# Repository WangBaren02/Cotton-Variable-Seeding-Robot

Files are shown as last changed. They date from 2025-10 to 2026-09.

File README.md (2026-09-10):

# 棉花变量播种机器人

Cotton Variable Seeding Robot

本项目面向棉花田间变量播种作业，构建了一套由移动底盘、距离与姿态感知、闭环运动控制、OpenMV 视觉节点、播种机构以及 PCB/机械设计资料组成的农业机器人系统。主控侧以 `STM32F407VG` 为核心，通过维特 IMU（WitMotion IMU）、6 路 Ultrasonic、2 路实际参与控制的 Encoder、GPIO 光电/作物检测信号和状态机、多组 PID，实现直行纠偏、垄端判断、换垄、出垄与停车等运动任务。

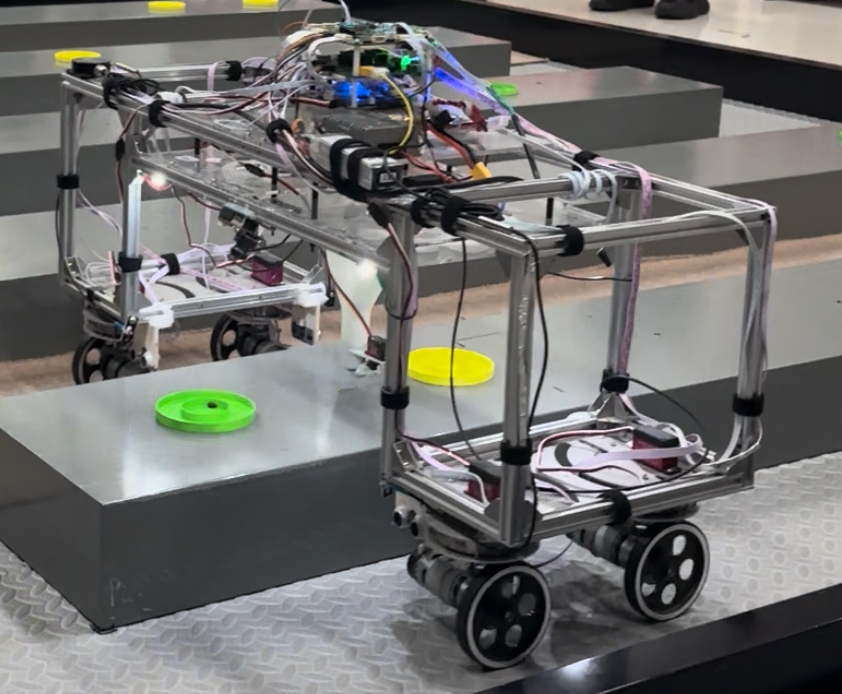
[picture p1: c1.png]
棉花变量播种机器人实机


▶ [点击观看棉花变量播种机器人实机演示](https://www.bilibili.com/video/BV1jCyhB8EZ5/)

## 项目简介

这个仓库不是单一的 MCU 示例程序，而是一个包含嵌入式控制、机器视觉、控制 PCB 和车体/播种机构设计资料的完整机器人项目。当前仓库中可以直接追踪的 Keil 工程位于 `CODE/USER/Prayer.uvprojx`，目标器件为 `STM32F407VG`，其运动控制主链包括：

- `TIM7` 周期中断调度任务；
- 维特 IMU 提供航向角反馈；
- 6 路 Ultrasonic 提供前方、左侧和右侧距离信息；
- TIM3/TIM5 对应的两路 Encoder 累计换垄位移；
- 4 路 DC Motor 和 4 路转向 Servo 执行底盘运动；
- `flag_step` 状态机选择不同的行驶、转向、换垄和出垄策略；
- OpenMV 通过颜色阈值与 Blob Detection 输出视觉/作业侧信号；
- `PCB板/` 与 `SOLIDWORKS 车体零件/` 保存控制板、车体、支架和播种机构资料。

## 技术栈与系统边界

| 模块 | 本仓库可核实的实现 |
| --- | --- |
| 主控 | `STM32F407VG`：`CODE/USER/Prayer.uvprojx` 的完整 Keil 工程目标 |
| 姿态感知 | 维特 IMU（WitMotion IMU）；主控通过 `USART2` 接收姿态数据并提取航向角 |
| 距离感知 | 6 路 Ultrasonic：`L1/L2`、`R1/R2`、`F1/F2`，使用 `TIM2` 与 `TIM9` 输入捕获 |
| 运动反馈 | 2 路实际被主程序初始化和读取的 Encoder：`TIM3`、`TIM5` |
| 边界/作物检测 | `LeftLight`、`RightLight` 两路 GPIO 信号，以及用于减速判断的 `PE15` GPIO 输入 |
| 视觉 | OpenMV：`RGB565`、`QVGA`、ROI、颜色阈值、均值滤波、Blob Detection |
| 底盘执行 | 4 路 DC Motor：`TIM1` 四通道 PWM + 方向 GPIO |
| 转向执行 | 4 路实际由 `Servo_Set_Angle()` 写入的转向 Servo：`TIM4` 四通道 PWM |
| 控制策略 | `flag_step` 状态机 + 航向 PID + 距离/纠偏 PID + 电机速度修正 |
| 工程资料 | Keil 工程、STM32 Standard Peripheral Library、OpenMV 脚本、PCB 工程压缩包、SolidWorks/SLDPRT/STL/DWG/DXF 文件 |

> 说明：PCB 资料和 `PCB板/TIPS.txt` 还提供了 `STM32F103RCT6` 作业板的证据，但仓库中没有找到对应的独立 Keil 源码工程。因此本文把它作为作业板/硬件资料证据说明，不把它包装成已由软件源码完整验证的第二套控制器。

## 项目亮点

- 使用 `STM32F407VG` 承担整车运动控制，`TIM7_IRQHandler()` 将状态判断、控制器选择、PWM 更新和 Ultrasonic 触发组织为周期任务。
- 维特 IMU 提供机器人航向角，主控以相对启动航向为目标，在直行、左右转向和倒车换垄阶段切换不同的航向控制器。
- 6 路 Ultrasonic 通过定时器输入捕获得到距离值，并经过限幅和均值滤波后参与垄端识别、侧向纠偏和换垄控制。
- 代码实际使用两路 Encoder 的累计位移完成换垄距离判断，避免把硬件资料中可能存在的编码器配置直接等同于当前固件使用数量。
- 多组 PID 分别面向航向、前方/侧方距离、转向 Servo 和电机速度修正，并根据 `flag_step` 选择当前作业状态所需的控制器。
- 4 路驱动电机、4 路转向 Servo、Ultrasonic、Encoder、光电信号和视觉/作业接口共同构成可追踪的机电闭环。
- OpenMV 采用轻量级颜色阈值与 Blob Detection，不依赖神经网络或深度学习模型。
- 仓库同时保留控制 PCB、车体连接板、Ultrasonic 支架、光电对管支架、Y 型作业机构、漏斗和作业机构上转盘等工程资料。

## 系统总体架构

```mermaid
flowchart TD
    ENV[棉田环境 / 垄道 / 作物目标] --> SENSE[多传感器感知]

    SENSE --> IMU[维特 IMU<br/>航向角]
    SENSE --> ULTRA[6 路 Ultrasonic<br/>L/R/F 距离]
    SENSE --> ENC[2 路 Encoder<br/>位移反馈]
    SENSE --> GPIO[GPIO 光电 / 作物检测]
    SENSE -. 视觉资料与作业接口 .-> MV[OpenMV<br/>RGB565 + Blob Detection]

    IMU --> MCU[STM32F407VG 主控]
    ULTRA --> MCU
    ENC --> MCU
    GPIO --> MCU
    MV -. GPIO / 作业板接口 .-> MCU

    MCU --> SCHED[TIM7 周期任务调度]
    SCHED --> FSM[flag_step 状态机<br/>任务状态选择]
    FSM --> PID[多组 PID / 运动控制策略]
    PID --> ACT[执行机构]
    ACT --> MOTOR[4 路 DC Motor]
    ACT --> SERVO[4 路转向 Servo]
    ACT -. 作业接口 .-> SEED[播种机构 / 作业板]
    MOTOR --> ROBOT[机器人运动、换垄与出垄]
    SERVO --> ROBOT
    ROBOT -. 运动反馈 .-> IMU
    ROBOT -. 距离 / 位移反馈 .-> ULTRA
    ROBOT -. Encoder 反馈 .-> ENC
```

图中的实线表示可以在当前 STM32F407 运动控制源码中直接追踪的链路；虚线表示仓库提供的 OpenMV、PCB 和播种机构资料与 GPIO/作业接口，但当前仓库没有提供完整的独立作业板固件和实车接线表。

## 实时控制与任务调度

`main.c` 的初始化顺序体现了主控的软件启动边界：Key、IO、LED、Servo PWM、Ultrasonic、OLED、Motor、`TIM7`、Encoder、PID 和 `USART1/USART2` 依次初始化。按下启动按键后，程序记录当前航向作为任务参考，写入各组航向 PID 的 `desired`，再置位 `flag_mission_start` 开始自动作业。

`TIM7_IRQHandler()` 内部使用多个软件计数器组织不同时间尺度的任务：

- 约 5 ms 控制分支：调用 `Detect_Flag_Step()`、`Detect_Flag_Slowdown()`、`Select_Servo_Angle()`、`Select_Motor_Speed()` 和 `Select_PID()`，随后统一写入 Servo 和 Motor 输出；
- 约 25 ms 触发一次 `Ultra_Trig()`，依次给 6 路 Ultrasonic 发送触发脉冲；
- 200 ms、500 ms、1000 ms、启动延时等标志用于状态切换后的停顿和减速节奏；
- OLED 实时显示航向、当前 `flag_step` 以及 6 路距离值，便于调试现场状态。

这种结构使“感知更新、状态判断、控制器选择、执行器更新”集中在固定周期内完成，而不是在主循环中用单一的 `Sensor → MCU → Motor` 直连逻辑表达。

## 运动控制系统

### 控制闭环

```mermaid
flowchart TD
    IMU[维特 IMU<br/>航向角] --> STATE[状态判断 / 控制策略]
    ULTRA[Ultrasonic<br/>前方与侧方距离] --> STATE
    ENC[Encoder<br/>换垄位移] --> STATE
    LIGHT[GPIO 光电 / 作物信号] --> STATE

    STATE --> SELECT["Select_PID()<br/>按 flag_step 选择控制器"]
    SELECT --> PID1[航向 PID]
    SELECT --> PID2[距离纠偏 PID]
    SELECT --> PID3[电机速度修正 PID]

    PID1 --> SERVO_CMD[Servo 角度增量]
    PID2 --> SERVO_CMD
    PID2 --> MOTOR_CMD[Motor 速度增量]
    PID3 --> MOTOR_CMD

    SERVO_CMD --> SERVO[4 路转向 Servo]
    MOTOR_CMD --> MOTOR[4 路 DC Motor]
    SERVO --> ROBOT[底盘运动]
    MOTOR --> ROBOT

    ROBOT -. 航向反馈 .-> IMU
    ROBOT -. 距离反馈 .-> ULTRA
    ROBOT -. 位移反馈 .-> ENC
```

### PID 的系统级分工

`pid.c` 中的 `PidObject` 统一保存目标值、误差、积分分离、积分限幅、微分项和输出限幅。README 只按控制目标进行抽象，不逐一罗列所有历史对象名：

- 航向闭环：直行、右向运动、左向运动、慢速转向、倒车和出垄阶段分别使用不同的航向 PID，将误差转换为 Servo 角度增量或四个电机的差速修正；
- 距离闭环：使用前方或侧方 Ultrasonic 距离与目标距离的误差，调整转向 Servo，使车体保持在目标通道/垄道关系中；
- 换垄闭环：在 `HuanLong()` 中使用 Encoder 的 `disA/disB` 作为位移判据，配合倒车电机方向、Servo 姿态和状态切换完成横向换垄；
- 电机速度闭环：PID 输出会叠加到 `SpeedL1/SpeedR1/SpeedL2/SpeedR2`，最终由 `Motor_Set_Speed()` 转换为四路 PWM 与方向信号；
- 状态相关控制：`Select_PID()` 根据 `flag_step` 决定当前使用航向、侧距、前距或换垄控制逻辑，避免所有阶段共用一组固定参数。

## 自动作业流程

源码中的 `flag_step` 不是单纯的数字流水号，而是对机器人作业动作的状态编码。按当前控制代码可还原为以下流程：

```mermaid
stateDiagram-v2
    [*] --> S0: 按键启动

    S0: 0 初始直行 / 启动延时
    S1: 1 右向转向或横移
    S2: 2 右侧换垄倒车
    S3: 3 左向转向或横移
    S4: 4 左侧换垄倒车
    S5: 5 右向转向或横移
    S6: 6 右侧换垄倒车
    S7: 7 左向转向或横移
    S8: 8 左侧换垄倒车
    S9: 9 最后一轮右向运动
    S10: 10 最后一轮左向 / 出垄准备
    S11: 11 出垄倒车
    S12: 12 停车

    S0 --> S1: F1/F2 距离达到垄端条件
    S1 --> S2: LightStop 检测到垄端光电事件
    S2 --> S3: HuanLong 中 disA 达到目标
    S3 --> S4: LightStop 检测到另一侧垄端
    S4 --> S5: HuanLong 中 disA 达到目标
    S5 --> S6: LightStop 检测到垄端
    S6 --> S7: HuanLong 中 disA 达到目标
    S7 --> S8: LightStop 检测到另一侧垄端
    S8 --> S9: HuanLong 中 disA 达到目标
    S9 --> S10: LightStop + 减速延时
    S10 --> S11: LightStop 完成最后边界判断
    S11 --> S12: ChuLong 中 disB 达到出垄距离
    S12 --> [*]
```

其中，`HuanLong()` 先让底盘倒车并读取两路 Encoder 的累计位移，达到当前状态对应的距离后停车、切换 Servo 姿态并进入下一状态；最后的 `ChuLong()` 使用另一方向的位移条件完成出垄并清除 `flag_mission_start`。

## 多传感器感知

### 维特 IMU

实际机器人使用维特 IMU。主控的 `USART2` 驱动接收固定长度姿态帧，检查 `0x55/0x53` 帧头后提取航向角数据，并减去启动时记录的 `start_YAW`，再根据初始朝向完成角度回绕。控制层中的历史变量和 PID 对象名称可能保留旧项目命名，但 README 按真实硬件统一写为维特 IMU（WitMotion IMU）。

### 6 路 Ultrasonic

`ultrasonic.h` 明确给出了六个测距通道：

- 左侧：`L1`、`L2`；
- 右侧：`R1`、`R2`；
- 前方：`F1`、`F2`。

`TIM2` 负责四路侧向回波输入捕获，`TIM9` 负责两路前向回波输入捕获。每一路根据上升沿/下降沿时间计算距离，并执行限幅和 `MeanFilterLimit()` 均值滤波。代码中的 `Ultra_Trig()` 依次触发六个通道；PCB 资料也特别提醒不要同时开启六路，以降低声波串扰。

### Encoder

当前 F407 主程序只调用：

- `TIM3_EncoderB_Init()`；
- `TIM5_EncoderA_Init()`；
- `Read_Encoder_Cnt()`。

`Encoders` 结构体保存 `cntA/cntB`、速度和累计位移 `disA/disB`。在换垄状态中，`disA` 和 `disB` 被清零并重新累计，用于判断横向移动和出垄距离。因此 README 写“2 路实际软件反馈”，不把历史 README 中的“4 encoders”当作当前固件事实。

### GPIO 光电与按键

`LeftLight` 和 `RightLight` 由两个 GPIO 输入宏提供，`LightStop()` 根据信号的边沿历史判断垄端事件；`PE15` 被读取为作物/颜色减速信号，在特定转向状态中触发 `Motor_SlowDown()`。此外，4 个按键用于启动、调试和手动操作，OLED 显示当前航向、状态和距离值。

仓库中还存在 `TFLuna` 驱动，但其 `LASER` 宏为关闭状态，当前 README 不把它列为已启用的主感知链路。

## 机器视觉

OpenMV 目录提供两份按左右位置命名的脚本：`RIGX.txt` 和 `LEFX.txt`。两份脚本都体现了以下视觉处理链：

1. 使用 `RGB565`、`QVGA`，关闭自动增益和自动白平衡；
2. 在 ROI 内分别使用绿色和黄色 `Color Threshold`；
3. 对图像做一次均值处理，并调用 `find_blobs()`；
4. 从候选 Blob 中选择最大色块，输出颜色和“多个色块”状态；
5. 通过 OpenMV 的 `P4/P5/P6` GPIO 输出二值信号。

这是一套基于颜色阈值和 Blob Detection 的轻量级视觉方案，不应描述为 AI、Deep Learning 或神经网络目标检测。目录中另有 `2022DFH（森哥）.txt` 历史版本，其中包含 `UART3` 和数据打包函数，但当前代码中的发送调用被注释，不能直接当作当前实机的串口视觉通信链路。

## 播种执行机构

播种部分在仓库中以“视觉脚本 + 作业接口 + PCB 资料 + 机械资料”的形式出现：

- OpenMV 脚本输出颜色/色块状态，供作业侧使用；
- F407 控制代码中的 `Detect_Flag_Mv()` 根据当前运动状态和左右光电信号驱动 `PE7/PE8` 作业接口；
- `PCB板/ProProject_智能农装大赛_2024-05-16.zip` 与 `PCB板/TIPS.txt` 提供了作业板资料，资料中出现 `STM32F103RCT6`；
- `SOLIDWORKS 车体零件/` 包含 Y 型作业机构、漏斗、作业机构上转盘、光电对管支架和相关 STL/SLDPRT 文件。

当前仓库没有找到 STM32F103 作业板对应的独立 Keil 源码，也没有一条从视觉输出到播种 Servo/转盘的完整可编译调用链。因此，本节展示已存在的系统集成证据，同时明确不把缺失的板间控制细节包装成当前 F407 工程已经完全实现的功能。

## 硬件与机械设计

仓库包含以下非纯软件工程资料：

- `PCB板/`：嘉立创 EDA 专业版工程压缩包及打开说明；资料文本中同时可见主控板 `STM32F407VGT6` 与作业板 `STM32F103RCT6` 的硬件证据；
- `SOLIDWORKS 车体零件/`：车体连接板、Ultrasonic 支架、光电对管支架、亚克力板图纸、Y 型作业机构、漏斗和上转盘等模型/加工文件；
- `c1.png`：机器人实机照片；
- `CODE/USER/Prayer.uvprojx`：可在 Keil 中打开的 STM32F407 主控工程。

PCB 目录中的说明还记录了六路 Ultrasonic 的串扰注意事项、作业板供电/端子约束以及实车接线可能与板上丝印存在差异。README 因此只使用源码和资料共同能证明的系统级表述，不把 PCB 丝印直接当作软件调用关系。

## 软件结构

```text
CODE/
├── CORE/                  # CMSIS Cortex-M4 头文件与启动文件
├── DMP/                   # 历史惯性传感器算法/协议相关资料
├── FWLIB/                 # STM32F4 Standard Peripheral Library
├── HARDWARE/
│   ├── ENCODER/           # Encoder 初始化、计数、位移与速度处理
│   ├── MOTOR/             # 四路电机 PWM 与方向控制
│   ├── SERVO/             # Servo PWM 与角度输出
│   ├── ULTRASONIC/        # 六路 Ultrasonic 触发与输入捕获
│   ├── USART*_DMA/        # USART DMA 收发驱动
│   ├── TIMER7/            # 周期调度定时器
│   ├── IO/                # 作业接口和 GPIO 输入/输出
│   ├── wit_c_sdk/         # 维特传感器协议 SDK 资料
│   ├── TFLUNA/            # TFLuna 驱动（当前宏配置未启用）
│   └── ...
├── OBJ/                   # Keil 编译生成的目标文件与报告
├── SYSTEM/
│   ├── CONTROL/           # 状态机、任务策略、行驶/换垄/出垄控制
│   ├── PID/               # PID 对象、更新算法和控制量映射
│   ├── delay/             # 延时服务
│   └── sys/               # 系统底层初始化
└── USER/
    ├── main.c             # 主程序、外设初始化和任务启动
    └── Prayer.uvprojx     # Keil 工程文件，目标为 STM32F407VG

摄像头识别代码（openmv）/
├── RIGX.txt               # 右侧命名的颜色识别脚本
├── LEFX.txt               # 左侧命名的颜色识别脚本
└── 2022DFH（森哥）.txt    # 历史版本，包含未启用的 UART 发送实现
```

目录结构保持项目原貌；本次维护只更新 README，不重命名、不移动、不清理源码或历史目录。

## 项目演示

▶ [点击观看：第九届农装 B 类国二获奖作品——棉花变量播种机器人](https://www.bilibili.com/video/BV1jCyhB8EZ5/)

## 项目成果

项目参加 **第九届国际大学生智能农业装备创新大赛**，获得 **全国二等奖**。相关竞赛要求可参考[官方竞赛页面](https://uiaec.ujs.edu.cn/news_show.php?id=190)。比赛背景是项目成果的一部分，但本 README 将重点放在机器人本体、控制链路和可验证的工程资料上。

## 仓库说明

- 本 README 按真实硬件将姿态感知写为维特 IMU（WitMotion IMU）；源码中的历史变量、PID 对象和目录名称不作为最终硬件架构依据。
- 主控软件证据以 `CODE/USER/Prayer.uvprojx`、`CODE/USER/main.c`、`CODE/SYSTEM/CONTROL/`、`CODE/SYSTEM/PID/` 和 `CODE/HARDWARE/` 中的实际调用关系为准。
- `STM32F103RCT6` 目前只有 PCB/作业板资料证据，未在仓库中找到同等完整的独立固件工程。
- OpenMV 目录有两份左右命名脚本，但当前仓库没有单独的摄像头部署清单和实车接线图；视觉节点的物理数量、主控归属和最终板间连接仍应以实车资料补充确认。
- `CODE/HARDWARE/` 中保留了多类历史驱动和编译产物；本 README 不把“目录存在”直接等同于“当前实机正在启用”。

## License

本仓库当前声明为 [MIT License](./LICENSE)。仓库内第三方库、器件厂商 SDK 和工具生成文件如带有独立许可或使用条件，应同时遵循其原始许可。

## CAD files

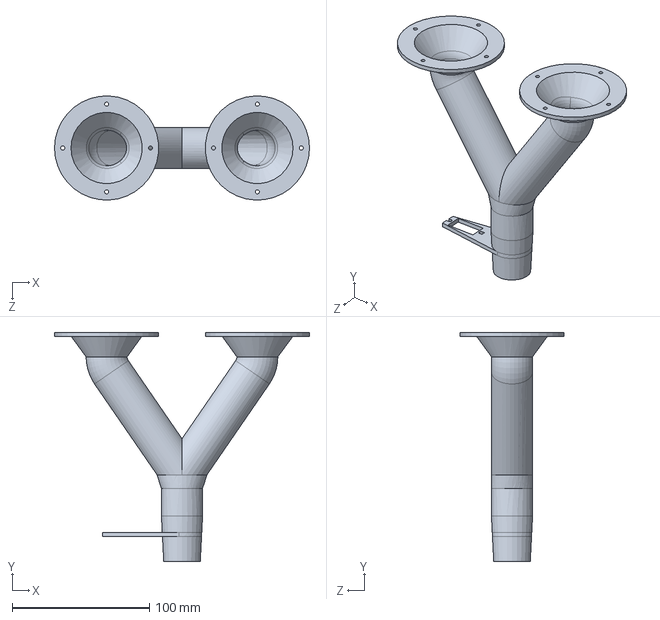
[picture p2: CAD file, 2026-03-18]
SOLIDWORKS 车体零件/Y型作业机构/最初版.SLDPRT
186.0 x 167.2 x 75.9 mm

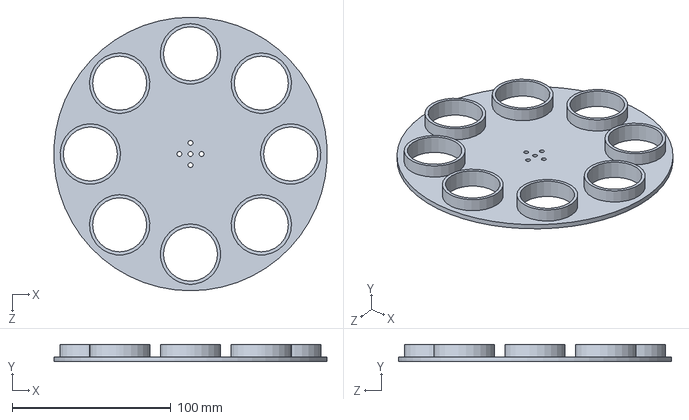
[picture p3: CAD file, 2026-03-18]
SOLIDWORKS 车体零件/作业机构上转盘/作业机构上转盘.SLDPRT
171.7 x 11.0 x 172.0 mm

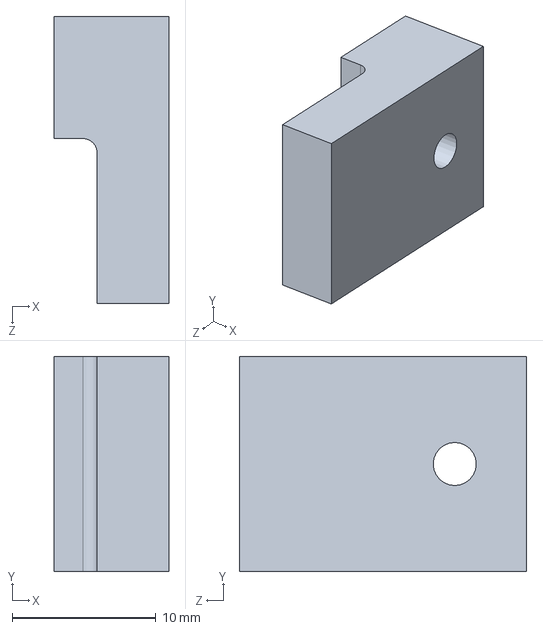
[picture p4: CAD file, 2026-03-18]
SOLIDWORKS 车体零件/光电对管支架/光电对管支架.SLDPRT
8.00 x 15.0 x 20.0 mm

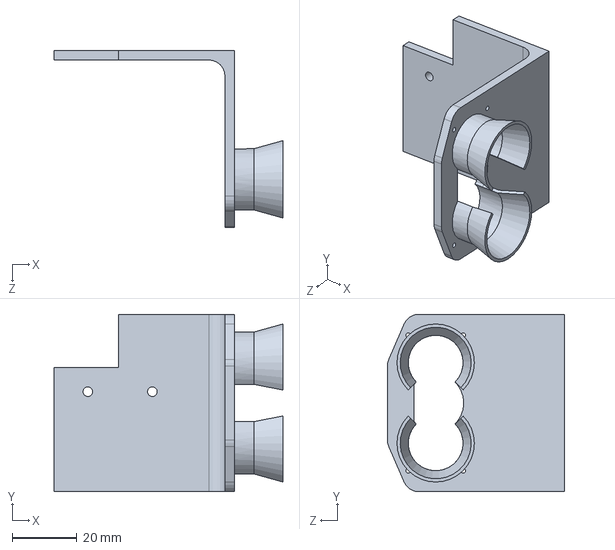
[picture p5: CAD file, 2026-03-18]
SOLIDWORKS 车体零件/超声波支架/RIGXXX.SLDPRT
71.0 x 55.0 x 55.0 mm

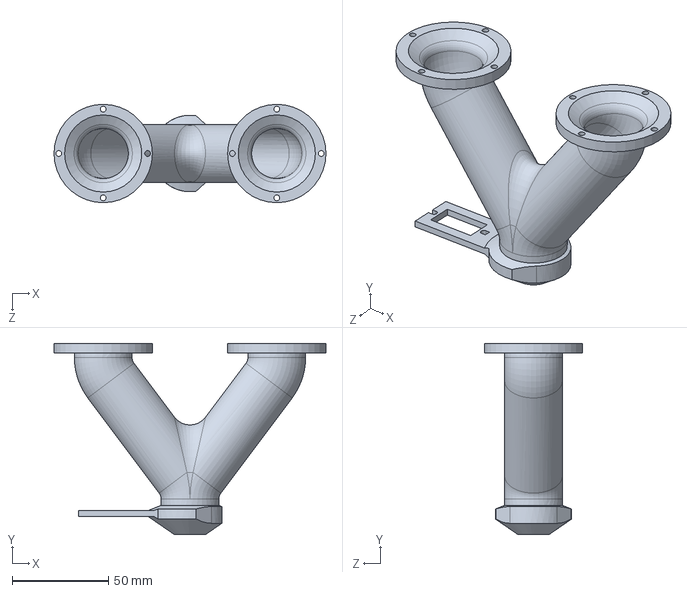
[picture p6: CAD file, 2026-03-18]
SOLIDWORKS 车体零件/Y型作业机构/漏斗XXXXX.SLDPRT
141.0 x 99.2 x 51.0 mm

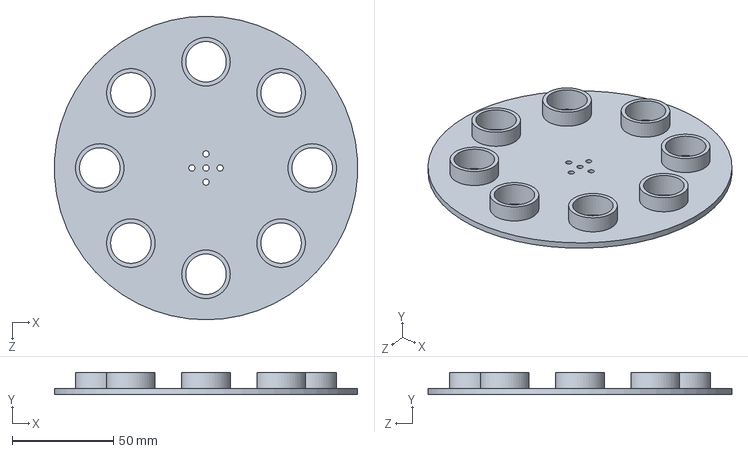
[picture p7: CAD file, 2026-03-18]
SOLIDWORKS 车体零件/作业机构上转盘/001X.SLDPRT
149.7 x 11.0 x 150.0 mm

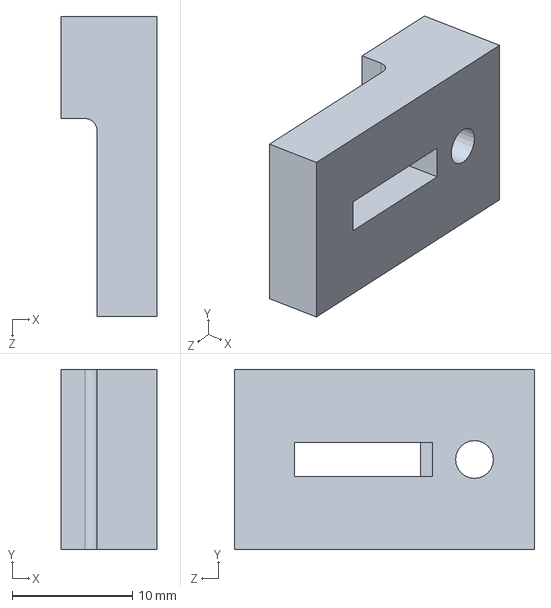
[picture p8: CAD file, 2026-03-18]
SOLIDWORKS 车体零件/光电对管支架/0005X.SLDPRT
8.00 x 15.0 x 25.0 mm

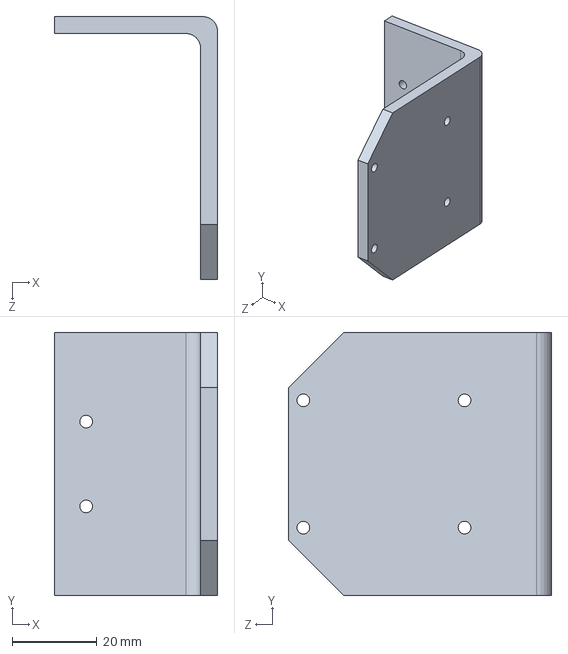
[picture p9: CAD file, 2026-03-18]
SOLIDWORKS 车体零件/超声波支架/MIDX.SLDPRT
38.5 x 62.0 x 62.0 mm

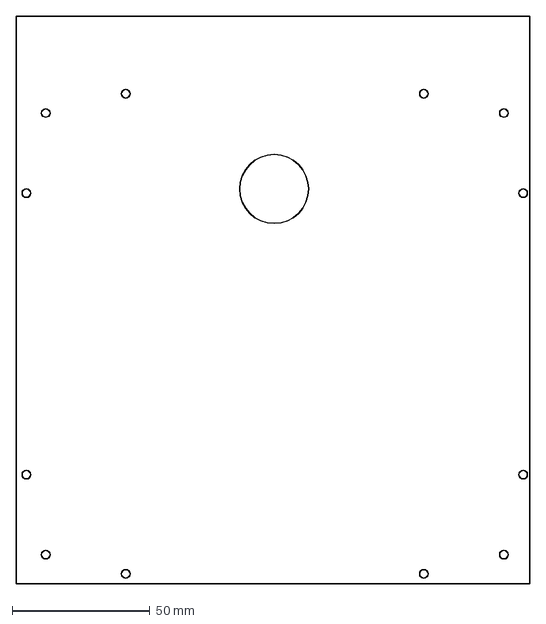
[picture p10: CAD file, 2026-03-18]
SOLIDWORKS 车体零件/亚克力板/02X.dxf
186.0 x 205.5 mm

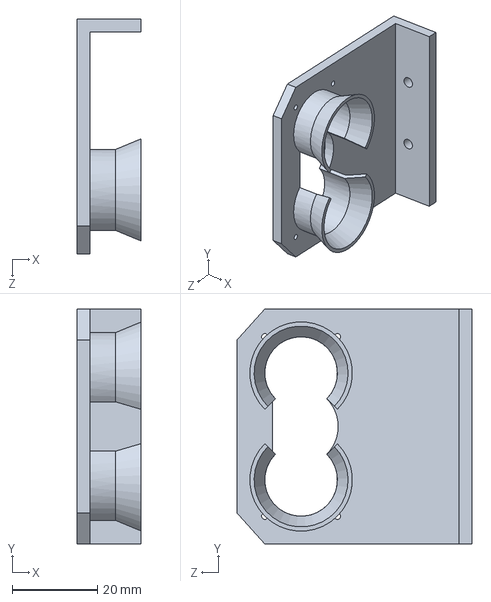
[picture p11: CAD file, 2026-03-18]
SOLIDWORKS 车体零件/超声波支架/MIDXXX.SLDPRT
15.0 x 55.0 x 55.0 mm

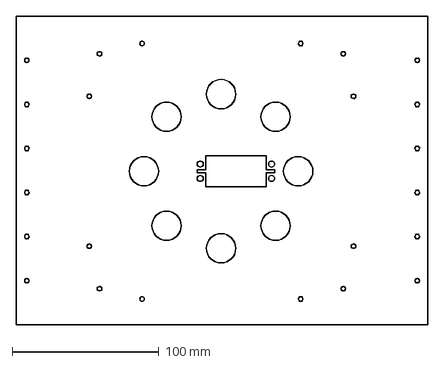
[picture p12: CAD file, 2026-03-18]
SOLIDWORKS 车体零件/亚克力板/01X.dxf
280.0 x 210.0 mm

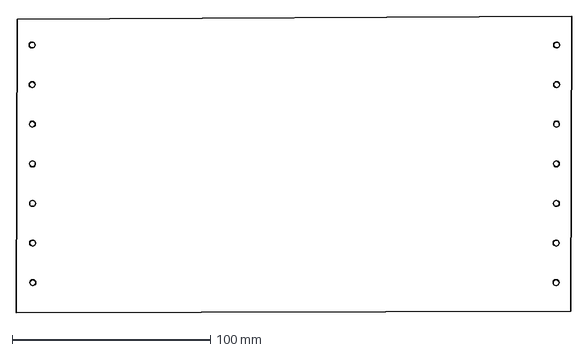
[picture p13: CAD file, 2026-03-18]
SOLIDWORKS 车体零件/亚克力板/00X.dxf
280.4 x 149.7 mm

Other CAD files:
SOLIDWORKS 车体零件/亚克力板/01.dwg
SOLIDWORKS 车体零件/轮子与框架连接板.DWG
SOLIDWORKS 车体零件/亚克力板/02.dwg
SOLIDWORKS 车体零件/打板子（2022）.SLDPRT
SOLIDWORKS 车体零件/超声波支架/LEFXXX.SLDPRT
SOLIDWORKS 车体零件/超声波支架/LEFX.SLDPRT
SOLIDWORKS 车体零件/Y型作业机构/漏斗XXXXX.STL
SOLIDWORKS 车体零件/亚克力板/00.dwg
SOLIDWORKS 车体零件/亚克力板/02X.dwg
SOLIDWORKS 车体零件/作业机构上转盘/001X.STL
SOLIDWORKS 车体零件/光电对管支架/0005X.STL
SOLIDWORKS 车体零件/光电对管支架/光电对管支架.STL
SOLIDWORKS 车体零件/超声波支架/LEFX.STL
SOLIDWORKS 车体零件/超声波支架/LEFXX.SLDPRT
SOLIDWORKS 车体零件/超声波支架/LEFXX.STL
SOLIDWORKS 车体零件/超声波支架/LEFXXX.STL
SOLIDWORKS 车体零件/超声波支架/MIDX.STL
SOLIDWORKS 车体零件/超声波支架/MIDXX.SLDPRT
SOLIDWORKS 车体零件/超声波支架/MIDXX.STL
SOLIDWORKS 车体零件/超声波支架/MIDXXX.STL
SOLIDWORKS 车体零件/超声波支架/MIDXXXX.STL
SOLIDWORKS 车体零件/超声波支架/RIGX.SLDPRT
SOLIDWORKS 车体零件/超声波支架/RIGX.STL
SOLIDWORKS 车体零件/超声波支架/RIGXX.SLDPRT
SOLIDWORKS 车体零件/超声波支架/RIGXX.STL
SOLIDWORKS 车体零件/超声波支架/RIGXXX.STL

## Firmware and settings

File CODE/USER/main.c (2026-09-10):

#include "stdio.h"
#include "string.h"
#include "sys.h"
#include "delay.h"
#include "stm32f4xx.h"
#include "control.h"
//#include "lamp.h"
#include "led.h"
#include "beep.h"
#include "key.h"
#include "oled.h"
#include "usart1_dma.h"
#include "usart2_dma.h"
#include "usart3_dma.h"
#include "uart4_dma.h"
#include "timer7.h"
#include "servo.h"
#include "ultrasonic.h"
#include "motor.h"
#include "encoder.h"
#include "pid.h"
#include "io.h"

float start_yaw=0;

int main(void)
{
	//系统初始化
	u8 key;
	float yaw_t;
	NVIC_PriorityGroupConfig(NVIC_PriorityGroup_2);
	delay_init(168);
	//BEEP_Init();
	Key_Init();
	IO_init();
	LED_Init();
	TIM4_Servo_PWM_Init(20000,84);
	Ultrasonic_Init();
	OLED_Init();
	OLED_Display_On();
	OLED_Clear();
	Motor_Init();
	TIM7_Init(1000,84);
	TIM3_EncoderB_Init(0xFFFF,1);
	TIM5_EncoderA_Init(0xFFFF,1);
	PID_Init();
	Motor_Stop();
	Motor_Set_Speed();
	USART1_Init(115200);
	USART2_Init(9600);

	Servo1_Increase = 0;
	Servo2_Increase = 0;
	Servo3_Increase = 0;
	Servo4_Increase = 0;
	SpeedL1_Increase = 0;
	SpeedR1_Increase = 0;
	SpeedL2_Increase = 0;
	SpeedR2_Increase = 0;
	SpeedL1_Increase_9250 = 0;
	SpeedR1_Increase_9250 = 0;
	SpeedL2_Increase_9250 = 0;
	SpeedR2_Increase_9250 = 0;
//	LED1_ON;
	
	Servo_Forw();
//	Servo_Turn();
	Servo_Set_Angle();
	while(1)
	{
		key = Key_Scan();
		if(key == 1)
		{
			start_YAW=yaw;					//记录下当前指南针原始中心角度
			if(start_YAW>-180 && start_YAW<-135)mode=2;
			else if(start_YAW<180 && start_YAW>135)mode=3;

			delay_ms(100);			//等待yaw稳定
			
			start_yaw=yaw;
			PID_9250_Forward_motor.desired = start_yaw;
			PID_9250_Forward.desired = start_yaw;
			PID_9250_Right.desired = start_yaw;
			PID_9250_Left.desired = start_yaw;
			PID_9250_Right_slow.desired = start_yaw;
			PID_9250_Left_slow.desired = start_yaw;
			PID_9250_Back.desired = start_yaw;
			PID_9250_Back_last.desired = start_yaw;
			PID_9250_Back_last_motor.desired = start_yaw;
			flag_mission_start = 1;
			flag_delay_1500ms = 1;	//step0时开始2s后以60%速度继续行驶
		}
		
		if(key == 2)
		{
			flag_step += 2;
//			PID_F1_Left_Servo.kp+=0.1;
//			PID_F1_Left_Servo.kp+=0.1;
		}
		
		if(key == 3)
		{
//			start_YAW=yaw;					//记录下当前指南针原始中心角度
//			if(start_YAW>-180 && start_YAW<-135)mode=2;
//			else if(start_YAW<180 && start_YAW>135)mode=3;
//			PID_9250_Right.kd+=2;
		}
		
		if(key == 4)
		{
			delay_ms(100);
//			Motor_Forw();
//			Motor_Right();
//			Motor_Left();
//			Motor_Back();
//			Motor_Set_Speed();
			Servo_Forw();
			Servo_Set_Angle();
		}
		
		
		delay_us(20);
		OLED_Show3FNum(10,0,yaw ,4,2,12);
		OLED_ShowIntNum(64,0,flag_step,2,12);
		//OLED_ShowIntNum(84,0,flag_huanlong,1,12);
		//OLED_ShowIntNum(96,0,flag_chulong,1,12);
		
//		OLED_Show3FNum(64,0 ,	PID_9250_Back.kp,3,1,12);
//		OLED_Show3FNum(10,12 ,	PID_9250_Back.kd,3,1,12);
		
		
//		OLED_Show3FNum(0,36,PID_9250_Right.kp,5,2,12);
//		OLED_Show3FNum(48,36,PID_9250_Right.kd,5,2,12);
/*********************************************************/
		OLED_Show3FNum(0,12,ultra_F1.DIS ,5,2,12);
		OLED_Show3FNum(48,12,ultra_F2.DIS ,5,2,12);

		OLED_Show3FNum(0,24,ultra_L1.DIS ,5,2,12);
		OLED_Show3FNum(48,24,ultra_L2.DIS,5,2,12);
		
		OLED_Show3FNum(0,36,ultra_R1.DIS ,5,2,12);
		OLED_Show3FNum(48,36,ultra_R2.DIS ,5,2,12);
    
//		OLED_Show3FNum(10,48,RightLightLast ,1,0,12);
//		OLED_Show3FNum(24,48,LeftLightLast ,1,0,12);
//		OLED_Show3FNum(36,48,RightLight ,1,0,12);
//		OLED_Show3FNum(48,48,LeftLight ,1,0,12);
//		OLED_Show3FNum(10,48,PID_F1_Left_Servo.kp ,1,3,12);
//		OLED_Show3FNum(48,48,PID_F1_Left_Servo.kd ,1,3,12);
	  OLED_Refresh_Gram();
	}
}

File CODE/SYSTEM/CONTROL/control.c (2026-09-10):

/* 23年东方红控制代码 
   编写人：周段文诚（原杨少文改）
	 时间：2023.4.25
	             头
			   R1----------L1
				 |            |
				 |            |
				 |            |
				 |            |
				 |            |
				 |            |
				 |            |
				 |            |
				 |            |
				 R2---------- L2
				       人
*/
/*
2024 沈子杰
		         F1头F2
			   L1----------R1
				 |            |
				 |            |
				 |            |
				 |            |
				 |            |
				 |            |
				 |            |
				 |            |
				 |            |
				 L2---------- R2
				       尾
							 人
*/
#include "stdio.h"
#include "string.h"
#include "control.h"
#include "sys.h"
#include "delay.h"
//#include "lamp.h"
#include "led.h"
#include "usart1_dma.h"
#include "usart2_dma.h"
#include "usart3_dma.h"
#include "uart4_dma.h"
#include "ultrasonic.h"
#include "oled.h"
#include "encoder.h"
#include "param.h"
#include "motor.h"
#include "pid.h"
#include "servo.h"
#include "io.h"

#define N 0.98
#define Move 185          //直行停车预留量420
#define move 320          //右行停车预留量 190
#define movez 320         //左行停车预留量 190
#define movez_last 350		//出垄前左行停车预留量

u8 parity						 = 0;								//判断奇数偶
float pitch, roll;
extern float yaw;
short aacx, aacy, aacz;
short gyrox, gyroy, gyroz;
u8 flag_step = 0;					//判断现在运行到了第几步的标志
u8 flag_yaw_new = 0;

char PIDOUT[20];
//int a=0;
/***********************************周段文诚 2022.9.14********************************************
0：入长垄          
1：→1
2：↓1
3：←1
4：↓2
5：→2
6：↓3
7：←2
8：↓4
9：→3
10：←3
11：出垄
12：停车
***********************************************************************************************/
u8 flag_mission_start 		= 0;				//按键按下后，进入控制函数的标志
u8 flag_huanlong 				  = 0;				//换垄标志，此flag=1时正在换垄
u8 flag_chulong 				  = 0;				//出笼标志，此flag=1时已经出笼
u8 flag_slowdown 				  = 0;				//减速标志，此flag=1时表示需要减速
u8 flag_zuowuslowdown 		= 0;				//减速标志，此flag=1时表示需要减速
u8 flag_found_zuowu				= 0;				//检测作物的标志，此flag=1时表示检测到作物，开始减速
u8 flag_delay					    = 0;				//延时标志，此flag=1时表示需要延时
u8 flag_delay_200ms				= 0;				//延时标志，此flag=1时表示需要延时200ms
u8 flag_delay_500ms				= 0;				//延时标志，此flag=1时表示需要延时500ms
u8 flag_delay_1000ms			= 0;				//延时标志，此flag=1时表示需要延时1000ms
u8 flag_delay_1500ms			= 0;				//延时标志，此flag=1时表示需要延时1500ms
u8 flag_delay_zuowu				= 0;				//延时标志，此flag=1时作物表示需要延时
u8 Color_SLOW							=0;
u8 flag_step0SLOW					=0;
uint8_t RightLightLast = 2;
uint8_t LeftLightLast = 2;

//float N_F_R = 1.0;
//根据不同步数选择舵机、电机的基本角度、速度
float Servo1_Base = 90, Servo2_Base = 90, Servo3_Base = 90, Servo4_Base = 90;
float Servo5_Base = 0, Servo6_Base = 0, Servo7_Base = 0, Servo8_Base = 0;
float SpeedL1_Base = 0, SpeedR1_Base = 0, SpeedL2_Base = 0, SpeedR2_Base = 0;
float SpeedL1_Base_c = 0, SpeedR1_Base_c = 0, SpeedL2_Base_c = 0, SpeedR2_Base_c = 0;
//根据PID的结果得到的舵机、电机的增量
float Servo1_Increase = 0, Servo2_Increase = 0, Servo3_Increase = 0, Servo4_Increase = 0;
float Servo5_Increase = 0, Servo6_Increase = 0, Servo7_Increase = 0, Servo8_Increase = 0;
float SpeedL1_Increase = 0, SpeedR1_Increase = 0, SpeedL2_Increase = 0, SpeedR2_Increase = 0;
float SpeedL1_Increase_9250 = 0, SpeedR1_Increase_9250 = 0, SpeedL2_Increase_9250 = 0, SpeedR2_Increase_9250 = 0;
//调试基础电机速度
//float Motor_Forw_test_L1 = 0, Motor_Forw_test_L2 = 0, Motor_Forw_test_R1 = 0, Motor_Forw_test_R2 = 0;
void TIM7_IRQHandler()
{

    static u16 time_1ms;
    static u16 time_5ms;
    static u16 time_10ms;
    static u16 time_25ms;
    static u16 time_50ms;
    static u16 time_200ms;
    static u16 time_500ms;
    static u16 time_1000ms;
    static u16 time_1500ms;
    static u16 time_zuowu;
    static u16 lamp_1000ms;

    if(TIM_GetITStatus(TIM7, TIM_IT_Update) == SET) //溢出中断
    {
        if(flag_mission_start == 1)		//按键按下后1、5、10、50ms的任务才能进行
        {
            time_1ms++;
            time_5ms++;
            time_10ms++;
            time_50ms++;
        }

        //下面的则不受按键的影响
        time_25ms++;


        if(flag_delay_200ms)								//延时专用
        {
            time_200ms++;
        }

        if(flag_delay_500ms)
        {
            time_500ms++;
        }

        if(flag_delay_1000ms)
        {
            time_1000ms++;
        }

        if(flag_delay_1500ms)
        {
            time_1500ms++;
        }

        if(flag_delay_zuowu)
        {
            time_zuowu++;
        }

//----------------------------------------------------------------------
        if(time_1ms == 1)
        {
            time_1ms = 0;

        }

//----------------------------------------------------------------------
        if(time_5ms == 5)
        {
					time_5ms = 0;
					Detect_Flag_Step();				//判断运行到第几步了

					Detect_Flag_Mv();
					flag_delay = (flag_delay_200ms || flag_delay_500ms || flag_delay_1000ms);

					if(!flag_delay)						//在不需要延时的时候才运行下面的步骤
					{
							Detect_Flag_Slowdown();		//判断是否需要减速
							Select_Servo_Angle();			//根据步数选择舵机基本角度
							Select_Motor_Speed();			//根据步数选择电机基本速度
							Select_PID();							//根据当前运行的步数来选择用那个PID

							Servo_Set_Angle();				//设置舵机角度
							Motor_Set_Speed();				//设置电机转速

							if(!flag_huanlong)
							{
									TIM5->CNT = 0;
									TIM3->CNT = 0;
									Encoders.disA = 0;
									Encoders.disB = 0;
							}

							if(flag_huanlong)
							{
									Read_Encoder_Cnt();
							}
					}
					if(!flag_delay)
					{
						if(flag_huanlong&&!flag_chulong)
						{
							HuanLong();								//换垄，当换完垄后，flag_step会+1
						}

						if(flag_chulong)
						{
							ChuLong();
						}
					 }

        }
//----------------------------------------------------------------------
        if(time_10ms == 10)
        {
          time_10ms = 0;
//					sprintf(PIDOUT,"%f,%f\n",ultra_F1.DIS,yaw);
//					sprintf(PIDOUT,"%f,%f\n",ultra_F1.DIS,ultra_F2.DIS);
//					USART1_DMATransfer((uint32_t *)PIDOUT,strlen(PIDOUT));
        }

//----------------------------------------------------------------------
        if(time_25ms == 25)
        {
            time_25ms = 0;

            Ultra_Trig();
						//Yaw_new();
        }

//----------------------------------------------------------------------
        if(time_50ms == 50)
        {
            time_50ms = 0;
        }

//----------------------------------------------------------------------
        if(time_200ms == 200)
        {
            time_200ms = 0;

            flag_delay_200ms = 0;
        }

//----------------------------------------------------------------------
        if(time_500ms == 450)
        {
            time_500ms = 0;

            flag_delay_500ms = 0;
        }

//----------------------------------------------------------------------
        if(time_1000ms == 680)	//700
        {
            time_1000ms = 0;

            flag_delay_1000ms = 0;
        }
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

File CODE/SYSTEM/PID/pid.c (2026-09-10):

#include "pid.h"
#include "math.h"
#include "motor.h"
#include "control.h"

#define n 1
#define speed_r_l 100
#define speed_r 80
#define speed_l 80

#define speed_r_9250 5
#define speed_l_9250 5

#define speed_r_9250_s 0.6
#define speed_l_9250_s 0.6

#define speed_r_back 120
#define speed_l_back 120

#define speed_r_j 100
#define speed_l_j 100

#define speed_r_r 100
#define speed_l_r 100

//电机A和电机B的转速闭环PID
PidObject PID_PWMA;
PidObject PID_PWMB;
//直走时的9250闭环
PidObject PID_9250_Forward;
PidObject PID_9250_Forward_motor;
//向右走的9250闭环
PidObject PID_9250_Right;
//向左走的9250闭环
PidObject PID_9250_Left;

//向右走的9250闭环
PidObject PID_9250_Right_slow;
//向左走的9250闭环
PidObject PID_9250_Left_slow;
//向后走的9250闭环
PidObject PID_9250_Back;
PidObject PID_9250_Back_last;
PidObject PID_9250_Back_last_motor;
//靠左前行时舵机进行闭环
PidObject PID_L1_For_Servo;
PidObject PID_L2_For_Servo;

//靠左后退时舵机进行闭环
PidObject PID_L1_Back_Servo;
PidObject PID_L2_Back_Servo;

//靠右前行时舵机进行闭环
PidObject PID_R1_For_Servo;

//靠右后退时舵机进行闭环
PidObject PID_R2_Back_Servo;
PidObject PID_R1_Back_Servo;
//舵机左行右行
PidObject PID_F1_Left_Servo;
PidObject PID_F2_Left_Servo;
PidObject PID_F1_Right_Servo;
PidObject PID_F2_Right_Servo;

//电机左行右行
PidObject PID_F1_Left_Motor;
PidObject PID_F2_Right_Motor;

PidObject PID_L1_For_Motor;
PidObject PID_L2_For_Motor;

//换垄时，用舵机保持和垄的固定距离
PidObject PID_Back_L_Servo;
PidObject PID_Back_R_Servo;

PidObject PID_L1_Left_Servo;
PidObject PID_R1_Right_Servo;

void PID_Init(void)
{
	PID_R1_Right_Servo.desired = R1 - R2;
	//比例
	PID_R1_Right_Servo.kp = 0.3;
	//积分
	PID_R1_Right_Servo.ki = 0;
	PID_R1_Right_Servo.integ_sep = 0;
	PID_R1_Right_Servo.dt = 0;
	PID_R1_Right_Servo.iLimit = 0;
	//微分
	PID_R1_Right_Servo.kd = 0.2;
	//输出限幅
	PID_R1_Right_Servo.outputLimit = 6;
	
	PID_L1_Left_Servo.desired = L1 - L2;
	//比例
	PID_L1_Left_Servo.kp = 0.3;
	//积分
	PID_L1_Left_Servo.ki = 0;
	PID_L1_Left_Servo.integ_sep = 0;
	PID_L1_Left_Servo.dt = 0;
	PID_L1_Left_Servo.iLimit = 0;
	//微分
	PID_L1_Left_Servo.kd = 0.2;
	//输出限幅
	PID_L1_Left_Servo.outputLimit = 6;
/*
*************************************
* 		电机A转速闭环PID参数初始化			
*************************************
*/	
	PID_PWMA.desired = 50;				//电机A的转速期望
	PID_PWMA.kp = 10;						//电机A转速闭环P
	PID_PWMA.ki = 0;
	PID_PWMA.integ_sep = 0;
	PID_PWMA.dt = 0;
	PID_PWMA.iLimit = 0;
	
/*
*************************************
* 		直走时9250PID参数初始化			
*************************************
*/	
	PID_9250_Forward.desired = 0;
	//比例
	PID_9250_Forward.kp = 1.7;
	//积分
	PID_9250_Forward.ki = 0;
	PID_9250_Forward.integ_sep = 0;
	PID_9250_Forward.dt = 0;
	PID_9250_Forward.iLimit = 0;
	//微分
	PID_9250_Forward.kd = 0.6;
	//输出限幅
	PID_9250_Forward.outputLimit = 6;
	
	PID_9250_Forward_motor.desired = 0;
	//比例
	PID_9250_Forward_motor.kp = 0;
	//积分
	PID_9250_Forward_motor.ki = 0;
	PID_9250_Forward_motor.integ_sep = 0;
	PID_9250_Forward_motor.dt = 0;
	PID_9250_Forward_motor.iLimit = 2000*n;
	//微分
	PID_9250_Forward_motor.kd = 0;
	//输出限幅
	PID_9250_Forward_motor.outputLimit = 500*n;
/*
*************************************
* 		右行时9250PID参数初始化
*************************************
*/
	PID_9250_Right.desired = 0;
	//比例
	PID_9250_Right.kp = 52;//62
	//积分
	PID_9250_Right.ki = 0;
	PID_9250_Right.integ_sep = 0;
	PID_9250_Right.dt = 0;
	PID_9250_Right.iLimit = 600*n;
	//微分
	PID_9250_Right.kd = 59;//82
	//输出限幅
	PID_9250_Right.outputLimit = 800*n;
	
	PID_9250_Right_slow.desired = 0;
	//比例
	PID_9250_Right_slow.kp = 400;
	//积分
	PID_9250_Right_slow.ki = 0;
	PID_9250_Right_slow.integ_sep = 2;
	PID_9250_Right_slow.dt = 1;
	PID_9250_Right_slow.iLimit = 600*n;
	//微分
	PID_9250_Right_slow.kd = 300;
	//输出限幅
	PID_9250_Right_slow.outputLimit = 800*n;
	
	PID_9250_Back_last_motor.desired = 0;
	//比例
	PID_9250_Back_last_motor.kp = 1000;
	//积分
	PID_9250_Back_last_motor.ki = 0;
	PID_9250_Back_last_motor.integ_sep = 0;
	PID_9250_Back_last_motor.dt = 0;
	PID_9250_Back_last_motor.iLimit = 600*n;
	//微分
	PID_9250_Back_last_motor.kd = 0;
	//输出限幅
	PID_9250_Back_last_motor.outputLimit = 2000*n;
/*
*************************************
* 		左行时9250PID参数初始化			
*************************************
*/	
	PID_9250_Left.desired = 0;
	//比例
	PID_9250_Left.kp = 28;
	//积分
	PID_9250_Left.ki = 0;
	PID_9250_Left.integ_sep = 0;
	PID_9250_Left.dt = 0;
	PID_9250_Left.iLimit = 600*n;
	//微分
	PID_9250_Left.kd = 36;
	//输出限幅
	PID_9250_Left.outputLimit = 800*n;
	
	PID_9250_Left_slow.desired = 0;
	//比例
	PID_9250_Left_slow.kp = 400;
	//积分
	PID_9250_Left_slow.ki = 0;
	PID_9250_Left_slow.integ_sep = 2;
	PID_9250_Left_slow.dt = 1;
	PID_9250_Left_slow.iLimit = 600*n;
	//微分
	PID_9250_Left_slow.kd = 300;
	//输出限幅
	PID_9250_Left_slow.outputLimit = 800*n;

/*
*************************************
* 		向后走时9250PID参数初始化			
*************************************
*/
/****************换垄****************/
	PID_9250_Back.desired = 0;
	//比例
	PID_9250_Back.kp = 1.824;
	//积分
	PID_9250_Back.ki = 0;
	PID_9250_Back.integ_sep = 0;
	PID_9250_Back.dt = 0;
	PID_9250_Back.iLimit = 0;
	//微分
	PID_9250_Back.kd = 0.556;
	//输出限幅
	PID_9250_Back.outputLimit = 6;
/****************出垄****************/
	PID_9250_Back_last.desired = 0;
	//比例
	PID_9250_Back_last.kp = 1.824;
	//积分
	PID_9250_Back_last.ki = 0;
	PID_9250_Back_last.integ_sep = 0;
	PID_9250_Back_last.dt = 0;
	PID_9250_Back_last.iLimit = 0;
	//微分
	PID_9250_Back_last.kd = 0.556;
	//输出限幅
	PID_9250_Back_last.outputLimit = 6;
/*
*************************************
* 		靠左前行时pid初始化			超声波
*************************************
*/
	PID_L1_For_Servo.desired = L1_F;
	//比例
	PID_L1_For_Servo.kp = 0.2;
	//积分
	PID_L1_For_Servo.ki = 0;
	PID_L1_For_Servo.integ_sep = 0;
	PID_L1_For_Servo.dt = 0;
	PID_L1_For_Servo.iLimit = 0;
	//微分
	PID_L1_For_Servo.kd = 0.1;
	//输出限幅
	PID_L1_For_Servo.outputLimit = 4;
	
	PID_L2_For_Servo.desired = L2_F;
	//比例
	PID_L2_For_Servo.kp = 0.2;
	//积分
	PID_L2_For_Servo.ki = 0;
	PID_L2_For_Servo.integ_sep = 0;
	PID_L2_For_Servo.dt = 0;
	PID_L2_For_Servo.iLimit = 0;
	//微分
	PID_L2_For_Servo.kd = 0.1;
	//输出限幅
	PID_L2_For_Servo.outputLimit = 4;
/*
*************************************
* 		靠左后退时pid初始化		  超声波
*************************************
*/
  PID_L1_Back_Servo.desired = L1;
	//比例
	PID_L1_Back_Servo.kp = 0.4;
	//积分
	PID_L1_Back_Servo.ki = 0;
	PID_L1_Back_Servo.integ_sep = 0;
	PID_L1_Back_Servo.dt = 0;
	PID_L1_Back_Servo.iLimit = 0;
	//微分
	PID_L1_Back_Servo.kd = 0.8;
	//输出限幅
	PID_L1_Back_Servo.outputLimit = 5;           //1

	PID_L2_Back_Servo.desired = L2;
	//比例
	PID_L2_Back_Servo.kp = 0.4;
	//积分
	PID_L2_Back_Servo.ki = 0;
	PID_L2_Back_Servo.integ_sep = 0;
	PID_L2_Back_Servo.dt = 0;
	PID_L2_Back_Servo.iLimit = 0;
	//微分
	PID_L2_Back_Servo.kd = 0.8;
	//输出限幅
	PID_L2_Back_Servo.outputLimit = 5;           //2
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
